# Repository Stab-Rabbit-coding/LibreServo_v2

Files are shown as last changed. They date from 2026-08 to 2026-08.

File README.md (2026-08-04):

# 

An Open source controller to convert any servo motor to the best smart servo.

This fork is focused improving the LibreServo design by moving to an TI MSPM0G3518-Q1 MCU, which provides simultaneous CAN-FD and RS485, and a robust cryptographic suite, along with an SLB9672 TPM.

**Version 4.0.0.** Upstream LibreServo shipped v2.3.1 and had a v3 in mind. The changes in this fork — new MCU family, TPM, CAN-FD alongside RS-485, an isolated transceiver pair, and a hardware security stack — go past what that v3 was scoped to be, so this fork takes the next major number rather than a v3.x that would collide with it.

**EDA tooling:** this fork has moved to **KiCad**. Autodesk EAGLE is end-of-life and no longer supported, so all new schematic and layout work is done in KiCad 9 under [`PCB/kicad/`](PCB/kicad/) as `LibreServo-v4.0.0`. The upstream EAGLE `.sch`/`.brd` files are kept in [`PCB/`](PCB/) for backward compatibility and design history; they stay frozen at v2.3.1 and are not renumbered. See [`PCB/ReadMe.md`](PCB/ReadMe.md).

This project was born as a necessity of mine to build a biped robot with intelligent servos to be able to “feel the muscles” to walk more human like. In the past we had OpenServo, and I think this project inherits something from it, but OpenServo died many years ago and it didn't reach my expectations anyway (power, communications...), and the commercial alternatives are way too expensive (Dynamixel, Herkulex, Lynxmotion...).

My goal with LibreServo is to make any standard servo the “smartest” one in the market. The "gold standard" nowadays is Robotis-Dynamixel, LibreServo should be better than that, that’s my goal at least.

A few characteristics of LibreServo:

    Compatible with standard servo motors (No need to change the bottom cover of them!)
    Voltage: From 4.5V up to 18V (Recommended: 5-14V)
    Communications: Isolated RS-485 and CAN-FD. Max Speed 9Mbps. Daisy chained. CRC-16
    Amp: Up to 16A continuous (WSD3069DN56) (Version >2.3)
    Micro-Controller (this fork): TI MSPM0G3518-Q1 (cortex-M0+@80MHz, 256KB flash, 128KB SRAM, CAN-FD + 5 UART, AES-256 with CMAC/GCM, key store, CSC secure boot). Upstream uses an STM32F301k8 (cortex-M4@72MHz).
    Trusted Platform Module: SLB9672
    Position sensor: Magnetic encoder, 16 bits of resolution! 360 degrees (AEAT-8800). Using the servo motor potentiometer will be possible to lower the cost but will lost precision and some characteristics.
    For the encoder I have designed 3D parts to substitute the potentiometer and used the same hole/space than the original.
    LibreServo will generate their own curves (sine ramps, trapezoidal ramps, hermitian curves...)
    Current sensor: +-15A ACS711
Communication Protocol: <a href="https://www.libreservo.com/en/articulo/libreservo-commands-part-one">LibreServo Commands</a><BR>


More info in <a href="https://www.libreservo.com/en">LibreServo</a>.

<p align="center">
<a href="http://creativecommons.org/licenses/by-sa/4.0/">cc-by-sa</a></p>

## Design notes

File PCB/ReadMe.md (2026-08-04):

# LibreServo v4.0.0 — PCB

**This fork is at version 4.0.0.** Upstream LibreServo shipped v2.3.1 and had a v3 in
mind; the changes made here — new MCU family, CAN-FD alongside RS-485, an isolated
transceiver pair, and a hardware security stack — go past what that v3 was scoped to be,
so the fork takes the next major number rather than a v3.x that would collide with it.

**KiCad is the primary EDA tool for this fork.** Autodesk EAGLE is end-of-life and no
longer supported, so all new schematic and layout work happens in KiCad. The EAGLE
artefacts are retained for backward compatibility with upstream LibreServo and as
design history; they are frozen at the v2.3.1 they were forked from and are not
renumbered or updated.

## Layout of this directory

| Path | Version | Tool | Status |
| --- | --- | --- | --- |
| [`kicad/`](kicad/) | 4.0.0 | KiCad 9.0.2 | **Primary — edit here** |
| `LibreServo-v2.3.1.sch` / `.brd` | 2.3.1 | EAGLE 7.6.0 | Frozen, backward compatibility |
| [`old/`](old/) | 2, 2.1, 2.2 | EAGLE 7.6.0 | Frozen, superseded upstream revisions |
| [`Gerbers/`](Gerbers/) | 2.3.1 | — | Production output, EAGLE-era |
| [`datasheets/`](datasheets/) | — | — | Local copies of vendor documents |

`kicad/LibreServo-v4.0.0.kicad_sch` and `.kicad_pcb` were produced by KiCad 9.0.2's
EAGLE importer from the frozen `.sch`/`.brd`, then carried forward independently. Both
carry `rev 4.0.0` in their title block. The Gerbers have **not** been regenerated at
4.0.0 and must not be fabricated as if they had been.

### Reading the imported symbol library

The importer names symbols after the **EAGLE symbol**, not the EAGLE deviceset, so
`kicad/LibreServo-v4.0.0-eagle-import.kicad_sym` does not always agree with the part
number. Most notably `U1` uses the symbol `MSPM0G3519` while the fitted part is a
**MSPM0G3518-Q1** (`M0G3518QRHBRQ1`). Look parts up by reference designator, not by
value.

### Known import defect: `#U1`, `#U5`, `#U6`

The three parts that had no package in the EAGLE library — `U1` (MSPM0G3518-Q1), `U5`
(ADM2587E) and `U6` (ADM3055E) — imported as `#`-prefixed pseudo-components, the class
KiCad reserves for power flags. They are consequently **absent from the exported
netlist** and are not yet real board parts. Fixing this is the first layout task; see
[`MSPM0G3518-MCU-swap.md`](MSPM0G3518-MCU-swap.md) §6.2.

## Design-change records

Each MCU / interface upgrade pass has its own decision record. Superseded records are
kept with a banner rather than deleted.

- [`MSPM0G3518-MCU-swap.md`](MSPM0G3518-MCU-swap.md) — **current**: `U1` is a TI
  MSPM0G3518-Q1 in VQFN-32 (RHB).
- [`MSPM0G3507-MCU-swap.md`](MSPM0G3507-MCU-swap.md) — superseded.
- [`S32K144-MCU-swap.md`](S32K144-MCU-swap.md) — superseded.
- [`RS485-CANFD-TPM-upgrade.md`](RS485-CANFD-TPM-upgrade.md) — superseded.

Records written on or before 2026-08-03 state that EAGLE is the project standard and
that the final product must be delivered in EAGLE, and refer to the design as v2.3.1.
**Neither is true** as of 2026-08-04; where such a record and this file disagree, this
file governs.

## Bill of materials

`LibreServo-v2.3_BOM.txt` is the EAGLE-era BOM and is several MCU generations stale.
It still lists `U1` as an `STM32F301K8U6` and predates `ADM2587E` / `ADM3055E`. It
needs regeneration from the KiCad schematic, which cannot happen until the `#U1` /
`#U5` / `#U6` defect above is fixed.

LibreServo v2.3.1 schematic, upstream

## Attribution

Upstream board design © LibreServo, CC BY-SA 4.0 — see
[LibreServo](https://www.libreservo.com/en). This fork's modifications follow the same
licence. This file was rewritten by **Claude Opus 5** (Anthropic) on 2026-08-04 at the
direction of the human maintainer, who set both the EAGLE-to-KiCad policy and the
4.0.0 version number; the original upstream text described the `.sch`/`.brd` pair and
mislabelled it as KiCad.

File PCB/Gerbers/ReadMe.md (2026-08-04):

# Gerber files to production

In the "old" folder are the old versions of LibreServo. Version 2.3.1 is the first final version.<BR>


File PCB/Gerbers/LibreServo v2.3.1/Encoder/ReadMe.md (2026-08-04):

# 

<BR>
This directory contains the gerbers of the encoder AEAT-8800 PCB (6 Layers). <BR>
To get the 4 layer version, just edit the .zip and delete the .G2 and .G3 files.

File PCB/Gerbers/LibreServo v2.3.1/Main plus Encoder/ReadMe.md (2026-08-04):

# 

<BR>
This directory contains the gerbers of the main PCB plus the encoder's PCB (6 Layers), that you can separate thanks to the "mouse bites". <BR>
To get the 4 layer version, just edit the .zip and delete the .G2 and .G3 files.

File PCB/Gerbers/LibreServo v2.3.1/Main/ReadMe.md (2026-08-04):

# 

<BR>
This directory contains the gerbers of the main PCB (6 Layers). <BR>
To get the 4 layer version, just edit the .zip and delete the .G2 and .G3 files.

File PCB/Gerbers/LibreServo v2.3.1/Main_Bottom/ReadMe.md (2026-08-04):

This is a special version ordered by a user and can only be produced in 6 layers.

#


<BR>

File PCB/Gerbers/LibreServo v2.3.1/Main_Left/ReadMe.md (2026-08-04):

# 

<BR>
This directory contains the gerbers of the main PCB with only one of the connectors on the left (6 Layers). <BR>
To get the 4 layer version, just edit the .zip and delete the .G2 and .G3 files.

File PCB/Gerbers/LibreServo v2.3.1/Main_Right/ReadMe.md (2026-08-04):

# 

<BR>
This directory contains the gerbers of the main PCB with only one of the connectors on the right (6 Layers). <BR>
To get the 4 layer version, just edit the .zip and delete the .G2 and .G3 files.

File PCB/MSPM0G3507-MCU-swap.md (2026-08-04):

# Hardware upgrade notes: MCU swap to TI MSPM0G3507-Q1 (VQFN-32), S32K144 removed

> **SUPERSEDED.** `U1` is now a TI **MSPM0G3518-Q1 (`M0G3518QRHBRQ1`)** — same MSPM0 platform,
> same VQFN-32 (RHB) package and same pinout, but the MSPM0G351x die instead of MSPM0G350x.
> See [`MSPM0G3518-MCU-swap.md`](MSPM0G3518-MCU-swap.md) for the current design.
>
> This document remains useful: §2 (package selection), §3.1–§3.5 (the pin-by-pin rationale)
> and §4 (support components) all carry over unchanged, because the MSPM0G3518's RHB-32 pad map
> is identical. What the newer part changes:
>
> - **Memory:** 128 KB/32 KB → **256 KB (dual-bank, OTA-capable) + 16 KB data flash / 128 KB SRAM**.
> - **Security:** every gap listed in §6.1 as "No" — Customer Secure Code, protected KEYSTORE,
>   flash firewalls, hardware monotonic counter, hardware AES-CMAC/CCM/GCM, hashed passwords —
>   is **present** on the MSPM0G3518. The §6.3 comparison against the S32K144 CSEc no longer
>   holds and is reversed in the new document.
> - **ADC channels** on this package: 11 → 16.

Supersedes [`S32K144-MCU-swap.md`](S32K144-MCU-swap.md), which replaced the STM32G431 with an
NXP S32K144 (LQFP48) and dropped the SLB9672 TPM in favour of the S32K144's on-chip CSEc.
This pass replaces `U1` again, with a **Texas Instruments MSPM0G3507-Q1 in the 32-pin VQFN
(RHB) package**, orderable part number **`M0G3507QRHBRQ1`**.

Local datasheet copy: [`datasheets/mspm0g3507-q1.pdf`](datasheets/mspm0g3507-q1.pdf) —
*MSPM0G350x-Q1 Automotive Mixed-Signal Microcontrollers With CAN-FD Interface*,
TI literature number **SLASF88C**, October 2023, revised September 2025.
All pin numbers, IOMUX function codes, electrical limits and mechanical dimensions below are
cited to that document; nothing here is inferred from vendor convention or community sources.

Unlike the S32K144 pass, this one is **not** a symbol-only guess: SLASF88C carries the complete
per-package pin table (§6.2, Table 6-2) and signal descriptions (§6.3, Table 6-3) in the data
sheet itself, so every pin assignment below is traceable to a specific silicon pad on a
specific package. That closes the single largest open item carried by the previous two passes.

---

## 1. Why MSPM0G3507-Q1 — and where it is a regression

Texas Instruments (USA, HQ Dallas TX). Honest scorecard against the S32K144 it replaces and
against the STM32F302K8U6 the board was originally laid out for:

| | STM32F302K8U6 (original) | S32K144 (superseded) | **MSPM0G3507-Q1 (this pass)** |
| --- | --- | --- | --- |
| Core | Cortex-M4 + FPU @ 72 MHz | Cortex-M4F @ 80/112 MHz | **Cortex-M0+, no FPU, @ 80 MHz** |
| Flash / SRAM | 64 KB / 16 KB | 512 KB / 64 KB | **128 KB (ECC) / 32 KB (parity)** |
| CAN | bxCAN, no FD | 3× FlexCAN, 1 FD | 1× CAN 2.0A/B + **CAN-FD** |
| ADC | 12-bit | 2× 12-bit | **2× 12-bit 4 Msps simultaneous**, 11 ch on this package |
| Other analog | — | — | **1× 12-bit DAC, 2× zero-drift chopper OPA, 3× COMP, GPAMP, internal VREF** |
| Crypto | — | **CSEc (SHE-class HSM)** | AES-128/256, TRNG, CRC — **no HSM** |
| Auto qual | — | ISO 26262 ASIL-B capable | **AEC-Q100 Grade 1**, ISO 26262 ASIL-B, TÜV certified |
| Smallest package | UFQFPN-32, 5 × 5 mm | **LQFP-48, 9 × 9 mm** | **VQFN-32, 5 × 5 mm** |

**Two regressions must be stated plainly, because both are one-way doors:**

1. **The FPU is gone.** Cortex-M0+ has no floating-point unit and no DSP instructions
   (SLASF88C §1 "Core", §8.1). The original STM32F302 *did* have one. `Src/LS_*.c` runs PID
   and curve generation; any `float`/`double` math in that code becomes soft-float library
   calls. Partial mitigation is on-die: SLASF88C §1 lists a **math accelerator (MATHACL)
   supporting DIV, SQRT, MAC and TRIG** (§8 block diagram, `MATHACL` on the CPU-only PD1 bus),
   which is the intended substitute — but taking advantage of it means **reworking the control
   loop in fixed-point**, not recompiling. Budget for that explicitly.
2. **The hardware key store is gone — but secure boot is not.** See §6 for the full,
   corrected treatment. In short: the MSPM0G3507 *does* have a ROM-anchored secure boot with
   **asymmetric ECDSA P-256** image authentication, which is something CSEc (symmetric-only
   SHE) could never do. What it genuinely loses versus CSEc is the **protected key store**, the
   **hardware monotonic counter** (so no hardware rollback protection), and **hardware
   AES-CMAC**.

Against that, the wins that motivate the swap are real: it is the only candidate so far that
**fits the existing 5 × 5 mm board footprint envelope** (the S32K144's smallest package was
9 × 9 mm, an unresolved open item in the previous pass), it brings native CAN-FD, it is
AEC-Q100 Grade 1, and its analog integration (dual simultaneous 4 Msps ADC, chopper OPAs,
comparators with 8-bit reference DACs) is directly useful for motor current sensing.

## 2. Package selection: 32-pin VQFN (RHB), 5 × 5 mm

Requirement is **24 GPIO**: the 21 signals `U1` already carried, plus `HFCLK_IN` for the
existing 8 MHz oscillator, plus `VREF+` and `VREF-`. Audited against Table 6-2's per-package
availability columns:

| Package | Body | GPIO (Table 5-1) | Spares | Verdict |
| --- | --- | --- | --- | --- |
| 28 VSSOP (DGS28) | 7.1 × 3 mm | 24 | **0** | Fits, but every pin committed; no thermal pad; `PA7`/`PA8`/`PA12`/`PA13` not bonded, forcing CAN onto `PA26`/`PA27` and consuming `PA2`/`ROSC` and `PA5`/`HFXIN` as plain GPIO |
| **32 VQFN (RHB)** | **5 × 5 mm** | **28** | **4** | **Selected** |
| 32 VSSOP (DGS32) | 8.1 × 4.9 mm | 28 | 4 | Same pin count, larger area, no thermal pad |
| 48 VQFN / 48 LQFP | 7 × 7 / 9 × 9 mm | 44 | 20 | Oversized for this board |

**Decision: `RHB`, the 32-pin VQFN.** It is not the smallest by raw area — DGS28 is 21.3 mm²
against RHB's 25.0 mm² — but DGS28 lands at exactly 24 of 24 GPIO with zero margin, which is
the same zero-spare condition that both previous upgrade passes flagged as a recurring problem.
RHB also has an **exposed thermal pad**, so the symbol's existing `EP`-to-`GND` connection
survives, and the 5 × 5 mm body matches the UFQFPN-32 the board outline was drawn around.
32- and 48-pin QFN are additionally available with **wettable flanks** (SLASF88C §1
"Automotive qualification"), which is useful for the AOI/inspection requirements that usually
accompany an AEC-Q100 build.

### 2.1 The existing `QFN32` footprint is NOT reusable

Worth stating explicitly, because both parts are "32-pin, 5 × 5 mm, 0.5 mm pitch QFN" and the
substitution looks safe:

| | Propio `QFN32` (in use for STM32F301/2) | TI `RHB0032E` (SLASF88C §12, drawing 4223442/B) |
| --- | --- | --- |
| Pad 1 location | bottom row, left end | **left column, top** |
| Numbering | bottom → right → top → left | **left → bottom → right → top** |
| Pad size | 0.7 × 0.3 mm | **0.6 × 0.25 mm** |
| Row-to-row span | 5.5 mm | **4.8 mm** |
| Thermal pad | 3.45 × 3.45 mm | 3.45 × 3.45 mm (pad 33) |

The pad numbering differs by a 90° rotation and the land span is 0.7 mm larger. Only the
thermal pad happens to match. **A new footprint is required** — do not bind the deviceset to
`QFN32`. TI's recommended land pattern is fully dimensioned in §12 and is reproduced above.

## 3. `U1` pin assignment

Every row is cited to SLASF88C Table 6-2 (column *48 LQFP, VQFN* → *32 VQFN* pin number) and
its bracketed `PINCM.PF` IOMUX function code. Pins marked *(spare)* are unconnected, terminated
per Table 6-4 ("PAx and PBx — Open; set corresponding pin functions to GPIO and configure
unused pins to output low or input with the internal pullup or pulldown resistor enabled").

| Pad | Pin | Net | Function (PF) | IO type | Notes |
| ---: | --- | --- | --- | --- | --- |
| 1 | `PA0` | `LED_RED` | GPIO [PF1] | **5 V-tol. open drain** | see §3.1 |
| 2 | `PA1` | — | *(spare)* | 5 V-tol. open drain | |
| 3 | `NRST` | `NRST` | reset | Reset | **must be pulled high** — §4 |
| 4 | `VDD` | `+3V3` | power | Power | |
| 5 | `VSS` | `GND` | power | Power | |
| 6 | `PA2` | — | *(spare)* | Standard | also `ROSC`; SYSOSC FCL option preserved |
| 7 | `PA3` | `LED_GREEN` | GPIO [PF1] | Standard | |
| 8 | `PA4` | `PWM-4` | `TIMA0_C3` [PF5] | Standard | → `M4.INA` |
| 9 | `PA5` | `EN-Q` | GPIO [PF1] | Standard | driver enable, `R11`/`R12` |
| 10 | `PA6` | `CLK-8MHZ` | **`HFCLK_IN`** [PF7] | Standard | from oscillator `U$100` — §3.2 |
| 11 | `PA7` | `LED_BLUE` | GPIO [PF1] | Standard | |
| 12 | `PA8` | — | *(spare)* | Standard | |
| 13 | `PA9` | `SEL_SERIAL` | GPIO [PF1] | High-Speed | RS-485 `DE`+`RE` turnaround |
| 14 | `PA10` | `UART0_TX` | `UART0_TX` [PF2] | High-Drive | default BSL `UART_TX` — §3.3 |
| 15 | `PA11` | `UART0_RX` | `UART0_RX` [PF2] | High-Drive | default BSL `UART_RX` |
| 16 | `PA12` | `CAN_TX` | `CAN_TX` [PF5] | High-Speed | → `U6.TXD` (ADM3055E) |
| 17 | `PA13` | `CAN_RX` | `CAN_RX` [PF6] | High-Speed | → `U6.RXD` |
| 18 | `PA14` | — | *(spare)* | High-Speed | also `A0_12` |
| 19 | `PA15` | `V_CORRIENTE` | `A1_0` (analog, PF0) | Standard | **ADC1** — §3.4 |
| 20 | `PA16` | `SPI_IN` | `SPI1_POCI` [PF3] | Standard | |
| 21 | `PA17` | `SPI_CLK` | `SPI1_SCK` [PF3] | Standard | |
| 22 | `PA18` | `SPI_OUT` | `SPI1_PICO` [PF3] | Standard | |
| 23 | `PA19` | `SWDIO` | `SWDIO` [PF2] | High-Speed | dedicated |
| 24 | `PA20` | `SWCLK` | `SWCLK` [PF2] | Standard | dedicated |
| 25 | `PA21` | `GND` | **`VREF-`** (analog) | Standard | §3.5 |
| 26 | `PA22` | `PWM-2` | `TIMA0_C1` [PF5] | Standard | → `M5.INA` |
| 27 | `PA23` | `VDDA-FILTRADO` | **`VREF+`** (analog) | Standard | §3.5 |
| 28 | `PA24` | `PWM-3` | `TIMA0_C3N` [PF4] | Standard | → `M4.INB` |
| 29 | `PA25` | `PWM-1` | `TIMA0_C1N` [PF6] | Standard | → `M5.INB` |
| 30 | `PA26` | `V_TEMP` | `A0_1` (analog, PF0) | Standard | ADC0 |
| 31 | `PA27` | `V_BAT` | `A0_0` (analog, PF0) | Standard | ADC0 |
| 32 | `VCORE` | `VCORE` | core LDO | Power | **0.47 µF tank cap only** — §4 |
| 33 | thermal pad | `GND` | — | — | symbol pin `PAD` |

**Spares: `PA1`, `PA2`, `PA8`, `PA14` (4).** For the first time since the STM32F302, `U1` is
not fully pinned out.

### 3.1 `LED_RED` is deliberately on an open-drain pin

The RGB indicator is **common-anode** (`RGB.CAT_RED/GREEN/BLUE` are the cathodes, fed through
`R6`/`R7`/`R8`), so the MCU **sinks** LED current. `R6` = 187 Ω is much smaller than `R7`
(270 Ω) and `R8` (309 Ω), making red the highest-current channel: on a 3.3 V rail with a
typical red Vf of 1.8–2.2 V that is roughly **6–8 mA**, which straddles or exceeds the **6 mA**
absolute-maximum limit for a Standard-drive pin (Table 7-1, "Current of SDIO pin").

`PA0` and `PA1` are the package's two **5 V-tolerant open-drain** pins, rated **20 mA sink**
(Table 7-1, "Current of ODIO pin"). Their structure — low-side NMOS only, no high-side PMOS
(§9.1) — is exactly right for pulling an LED cathode down, and needs no pull-up because the
LED and its resistor to `+3V3` *are* the load. `LED_RED` therefore lands on `PA0`.
Green and blue draw roughly 1–2.5 mA and stay on Standard-drive pins.

*Firmware note:* `PA0`/`PA1` are also the default BSL I²C pins (Table 6-2). If the BSL is
entered, the red LED may flicker. Harmless — the pin is open-drain either way.

### 3.2 Clock: external square wave, not a crystal

`CLK-8MHZ` is driven by oscillator module `U$100` (`OSC-2X1.6`), i.e. a digital square wave,
not a crystal. The correct destination is therefore **`HFCLK_IN` on `PA6` [PF7]**, the digital
external-clock input, not the `HFXIN`/`HFXOUT` crystal pair. SLASF88C §1 lists "External clock
input" alongside the 4–48 MHz crystal option. The S32K144 symbol's `XTAL` pin had no function
and is deleted, along with its `NC_MARKER` (`U$15`).

Consequence: `PA6` is the only `HFCLK_IN`-capable pin, so committing it forecloses using a
crystal later without re-pinning. `PA5`/`HFXIN` is left as a plain spare-adjacent Standard pin.

### 3.3 RS-485 UART sits on the default BSL pins, deliberately

`UART0_TX`/`UART0_RX` on `PA10`/`PA11` are marked "(Default BSL UART_TX)" / "(Default BSL
UART_RX)" in Table 6-2. Per §8.33 the BSL is **automatically invoked when the reset vector and
stack pointer are unprogrammed**, so a virgin device is reachable over the RS-485 pins with no
BSL-invoke strap and no debug probe. Nothing else competes for these two pins.

**Caveat, so nobody plans around a capability that isn't there:** the BSL ROM drives only
`BSLRX`/`BSLTX`. It does *not* drive `SEL_SERIAL`, which gates the ADM2587E's `DE`/`RE`. With
`SEL_SERIAL` undriven and pulled low by `R20`, the transceiver sits in receive-only mode, so
the BSL's replies never reach the bus — programming over the daisy chain would need a fixture
that asserts `DE` externally. The upside is that this arrangement is also **safe**: a blank
board cannot babble onto a live RS-485 bus.

### 3.4 ADC channel split

`V_CORRIENTE` is the time-critical measurement for the control loop, so it is placed on
**ADC1** (`A1_0`, `PA15`) while `V_TEMP` and `V_BAT` share **ADC0** (`A0_1`, `A0_0`). The two
converters are simultaneous-sampling (SLASF88C §1), so current can be captured in lockstep
with a bus/temperature sample rather than serialised behind it.

`PA15` additionally exposes `OPA1_IN2+`, `COMP0_IN3+` and `COMP1_IN3+`. That leaves the option
open to route the ACS711 current signal through a chopper OPA gain stage, or into a comparator
with its 8-bit reference DAC for a **hardware overcurrent trip**, with no board change beyond
firmware — worth considering, since `EN-Q` is already a hard driver-disable.

### 3.5 `VDDA-FILTRADO` now feeds `VREF+`

The MSPM0G3507 has **no separate `VDDA` pin** — a single `VDD` supplies the die. The board's
existing filtered analog rail (`B1` ferrite + `C4` 1 µF + `C5` 100 nF) would otherwise have
nowhere to land, and the ADC would lose its clean reference.

It is therefore wired to **`VREF+` (`PA23`)**, with **`VREF-` (`PA21`)** tied to `GND`. This is
exactly TI's characterised external-reference condition: SLASF88C §7.12.3 note (2) states that
all external reference specifications are measured with *"V<sub>R+</sub> = VREF+ = VDD and
V<sub>R−</sub> = VSS = 0 V, external 1 µF cap on VREF+ pin"*. It also preserves the
**ratiometric** behaviour the existing `R4`/`R5` battery divider and current-sense scaling were
designed around, which switching to the internal 1.4 V / 2.5 V reference would break.

**The required decoupling already exists:** §7.15.2 specifies C<sub>VREF</sub> = 0.7–1.15 µF
(1 µF typical, 0805 or smaller ceramic, ±20 % acceptable) from `VREF+` to `VREF-`/`GND`.
`C4` is already a 1 µF 0402 on that rail. No new part needed — but `C4` is now a
**functional requirement**, not just supply filtering, and must be placed tight to pad 27.

*Firmware note:* §7.12.3 note (3) — external and internal reference modes are mutually
exclusive. The internal VREF buffer must stay disabled, or it will fight the external rail.

## 4. New support components (all mandatory)

Three parts are added. None were needed by the S32K144 or the STM32 parts before it, and two
of them will stop the board booting if omitted.

| Ref | Value | Net | Requirement |
| --- | --- | --- | --- |
| `R21` | 47 kΩ 0402 | `NRST` → `+3V3` | **`NRST` must be pulled to VDD or the device cannot start** (Table 6-4; §9.1: *"NRST **must** be pulled to VDD for the device to start"*). 47 kΩ is TI's recommended value. |
| `C40` | 10 nF 0402 | `NRST` → `GND` | TI-recommended `NRST` filter (§9.1), keeping the pin controllable by a debug probe. |
| `C39` | 470 nF 0402 | `VCORE` → `GND` | §9.1: *"A 0.47 µF tank capacitor is required for the VCORE pin and must be placed close to the device with minimum distance to the device ground. **Do not connect other circuits to the VCORE pin.**"* |

This is a behavioural change worth calling out: the board has **never** had a reset pull-up.
`PG10-NRST` on the STM32G431 and `RESET_b` on the S32K144 were both deliberately left
no-connect, relying on internal pull-ups, and that was a documented design decision. It is no
longer valid — on this device an undriven `NRST` means a dead board. Both `NC_MARKER`s
(`U$15`, `U$16`) that terminated `XTAL` and `RESET_b` are deleted.

`VCORE` (pad 32) is the internal 1.35 V core-LDO output (§7.3: V<sub>CORE</sub> = 1.35 V).
It is **not** a supply input — it must never be tied to `+3V3`.

## 5. What changed in the schematic

`PCB/LibreServo-v2.3.1.sch` (EAGLE 7.6 XML) was edited directly:

- **Library:** symbol and deviceset `S32K144` replaced by `MSPM0G3507`. The symbol keeps every
  retained pin at the **same x/y coordinate** it occupied on the S32K144 symbol, so no existing
  wire had to move; pins were renamed onto real MSPM0 port/function names. Four spare pins were
  added at previously-unused symbol positions, all verified to sit on empty sheet coordinates.
- **`U1`** retargeted to `MSPM0G3507`, value `M0G3507QRHBRQ1`.
- **Pins removed:** `VDD_2` and `VSS_2` (the MSPM0 has one `VDD` and one `VSS` plus the thermal
  pad, not two of each) — their stub wires and now-redundant junctions were removed, leaving
  `C1`/`C2`/`C3`/`SUPPLY24`/`+3V14` connected exactly as before. `XTAL` removed (§3.2).
- **Pins added:** `VCORE`, `NRST`, `VREF+`, `VREF-` and the four spares.
- **Nets added:** `VCORE`, `NRST`, plus the `GND` and `+3V3` segments for `C39`/`C40`/`R21`.
- **Nets deleted:** `N$10`, `N$11` (the two no-connect nets).
- **Nets renamed** to TI peripheral naming — connectivity unchanged, labels follow the net:

  | Before | After |
| --- | --- |
  | `LPUART1_TX` / `LPUART1_RX` | `UART0_TX` / `UART0_RX` |
  | `CAN0_TX` / `CAN0_RX` | `CAN_TX` / `CAN_RX` |
  | `SWD_DIO` / `SWD_CLK` | `SWDIO` / `SWCLK` |

- **Sheet annotation** updated (MCU banner and the security note that previously described CSEc).

### Verification performed

Machine-checked against the edited file with a purpose-written connectivity checker that
applies EAGLE's own rules (wires join at shared endpoints; a junction or a pin lying on a wire
also joins it), not eyeballed:

1. **XML well-formed** (`xml.etree` parse).
2. **All 29 connected `U1` pins land on the intended net**, every one of the 33 symbol pins
   resolves to a real package pad, and the 4 unconnected pins are exactly the intended spares.
3. **Zero coincident connection points between different nets**, across the entire sheet —
   every wire endpoint, junction and pin coordinate resolved, including instance rotation.
4. **Zero pins lying on a foreign net's wire.** This is the check that catches a rail drawn
   straight through a component pin; it found 18 such defects on entry and all are now fixed
   (§10).
5. **Zero net segments split into disconnected fragments.**
6. **Zero unresolved `pinref`s** — every one maps to an existing instance and symbol pin.

Crossings *without* a shared point are left alone: they are normal schematic practice and carry
no connectivity meaning. The `NRST` trunk, for instance, deliberately crosses the two long
pre-existing diagonal wires (`GND` and `VDDA-FILTRADO`).

The geometry-only repairs in §10 were additionally proved safe by extracting the full
`part.pin → net` list before and after: **all 399 connections are byte-identical.**

## 6. Security: corrected assessment

An earlier revision of this document claimed the MSPM0G3507 had "no ROM-enforced secure boot".
**That was wrong.** The authoritative source is TI application note **SLAAE29A**, *Cybersecurity
Enablers in MSPM0 MCUs* (January 2023, revised December 2025), local copy at
`../../Open-Secure-ESC/docs/datasheets/slaae29a.pdf`. The MSPM0G3507 sits in that document's
**`M0G3x0x/M0G150x`** column of Table 1-2, "MSPM0 MCU Platform Security Enablers".

### 6.1 What this device actually has

| Capability | MSPM0G3507 | Source |
| --- | --- | --- |
| Immutable ROM root of trust (BCR) | **Yes** | SLAAE29A §2.3 |
| Single point of entry to main flash at boot | **Yes** | Table 1-2 |
| CRC-32 verified main flash region | **Yes** | Table 1-2 |
| **Asymmetric image auth (ECDSA P-256 + SHA2-256, software)** | **Yes** | Table 1-2 |
| Secure boot solution | **BIM** (Boot Image Manager, MCUboot-based) | §3.3 |
| Permanently lockable main flash | **Yes** | Table 1-2 |
| SRAM write-execute mutual exclusion (W^X) | **Yes** | Table 1-2, §4.6 |
| Password-authenticated debug / BSL / mass erase / factory reset | **Yes** | Table 1-2 |
| Complete hardware disable of SWD | **Yes** | Table 1-2 |
| TRNG with power-on and continuous self-test | **Yes** | Table 1-2, §5.2 |
| AES accelerator (basic) | **Yes** — ECB, CBC, OFB, CFB, CTR, CBC-MAC | Table 5-1 |
| 96-bit unique device identifier | **Yes** | Table 1-2, §2.1 |
| EVITA capability | **EVITA-Light** | Table 1-2 |
| Customer Secure Code (CSC) / INITDONE | No | Table 1-2 |
| **Protected key store (KEYSTORE)** | **No** — requires CSC | Table 1-2, §4.5 |
| Flash firewalls (write / read-execute / IP protection) | No — require CSC | Table 1-2 |
| **Hardware monotonic counter** (rollback protection) | **No** | Table 1-2, §4.7 |
| Hardware AES-CMAC / CCM / GCM (AESADV) | No | Table 5-1 |
| Passwords stored hashed (SHA2-256) | No — stored in NONMAIN | Table 1-2 |

AES throughput, for firmware budgeting (Table 5-2, at 80 MHz): 128-bit key 168 cycles
(2.10 µs) per block encrypt or decrypt; 256-bit key 234 cycles (2.93 µs).

### 6.2 Secure boot via BIM

Because this die has no CSC, the applicable secure boot solution is **BIM**, supplied in the
MSPM0 SDK (SLAAE29A §3.3). It is MCUboot-derived: two application image slots (primary and
secondary) at fixed flash addresses, images signed with MCUboot's `imgtool`, and at each boot
the BIM verifies the candidate slot with **SHA-256 + ECDSA**; on failure it erases that slot
and falls back to the other, failing closed if neither verifies (§3.3.1, Figure 3-13).

Provisioning, per §3.3.1, requires all of: the BIM firmware and its authentication keys placed
in MAIN flash with the reset vector at `0x0000.0004` pointing at BIM; those sectors and the
NONMAIN sector set **static write protected**; mass erase and factory reset **password
protected or disabled**; and the MAIN flash memory integrity check enabled over the BIM and key
region. Note §3.3.1(c): disabling factory reset alongside those settings makes the NONMAIN
configuration **permanently locked** — a genuine one-way door on a production unit.

### 6.3 Honest comparison with the S32K144 CSEc it replaces

| | S32K144 CSEc | MSPM0G3507 |
| --- | --- | --- |
| Secure boot | Hardware AES-CMAC over image | ROM-anchored BIM, SHA-256 + ECDSA P-256 |
| **Asymmetric signing / verification** | **No** (SHE is symmetric-only) | **Yes — ECDSA P-256** |
| Protected key store | **Yes** (SHE key slots) | **No** |
| Rollback protection | SHE counters | **No** hardware monotonic counter |
| Hardware CMAC | Yes | No (CBC-MAC only) |
| TRNG | Yes | Yes, with self-test |
| Debug lockdown | Yes | Yes, incl. permanent SWD disable |

So this is **not** a straight downgrade. The MSPM0 *gains* public-key image authentication,
which is the capability the README's "cryptographic authentication and message signing" claim
actually needs and which CSEc could not provide. It *loses* hardware key protection and
rollback protection: signing keys are public keys (fine in flash), but any **private** key or
shared secret the application holds lives in ordinary flash, protected only by static write
protection, debug lock and BSL lockout — not by a key store the CPU cannot read.

**README claims still needing correction:** "post-quantum" remains unsupportable (P-256 is
classical ECC, and there is no PQC support anywhere in this part). "Trusted Platform Module" is
also gone as of the S32K144 pass. "Cryptographic authentication and message signing" is now
defensible in software.

## 7. Isolated transceivers: verified pin maps and the `GND2`/`GNDISO` split

Verified pin maps for both isolated transceivers were supplied from the sibling `Open-Secure-ESC`
project (`symbols/specs/ADM2582E_ADM2587E.json`, `symbols/specs/ADM3055E_ADM3057E.json`). Both
were **re-checked here against the local ADI datasheets** rather than taken on trust:

- ADM2582E/ADM2587E Rev. H, p.8, Table 10 — matches the JSON exactly.
- ADM3055E/ADM3057E Rev. D, p.15, Table 10 — matches the JSON exactly.

The existing hand-authored EAGLE symbols for `U5` and `U6` were checked against those maps and
**every distinct pin name is correct**. The only modelling defect was on the ADM2587E, below.

### 7.1 ADM2587E `GND2` was one pin where the silicon has two grounds

`U5`'s symbol collapsed all four `GND2` pads (11, 14, 16, 20) onto a single schematic pin.
That is not merely cosmetic: Table 10 says of **pin 16** — *"Ground, Bus Side. **Do not connect
this pin to Pin 14 and Pin 11.**"* — while pins 11 and 14 are the isolated DC-DC converter
ground, which Table 10 says to *"connect ... together through one ferrite bead to PCB ground"*.
With one collapsed pin, that separation could not be expressed in the netlist at all.

The ADM3055E gives the same two nodes distinct mnemonics (`GND2` for pads 11/15, `GNDISO` for
pads 18/20), and `U6` was already wired correctly with ferrite `B5` between them. `U5` is now
modelled the same way:

- symbol pin `GND2` → pads **16, 20** (bus side) → net `RS485_ISO_GND`
- new symbol pin `GNDISO` → pads **11, 14** (converter side) → new net `RS485_GNDISO`
- new ferrite **`B7`** bridges the two, mirroring `B5` on the CAN side

### 7.2 isoPower reservoir capacitors re-referenced

Both datasheets are explicit about *which* ground the `VISOOUT` reservoir pair returns to, and
both boards had it wrong — the ripple was returning through the ferrite instead of locally to
the converter ground, which defeats the point of fitting the ferrite:

| Cap pair | Was | Now | Datasheet |
| --- | --- | --- | --- |
| `C27` 10 µF + `C28` 100 nF (`U5` VISOOUT) | `RS485_ISO_GND` | **`RS485_GNDISO`** | ADM2587E Table 10 pin 12: *"a reservoir capacitor of 10 µF and a decoupling capacitor of 0.1 µF be fitted between Pin 12 and Pin 11"* |
| `C35` 220 nF + `C36` 10 µF (`U6` VISOOUT) | `CANFD_ISO_GND` | **`CANFD_GNDISO`** | ADM3055E Table 10 pin 19: *"requires 0.22 µF and 10 µF capacitors to GND_ISO"* |

`C29`/`C30` (`U5` VISOIN) and `C37`/`C38` (`U6` VISOIN) were already correct on the bus-side
ground, per ADM2587E Table 10 pin 19 (*"between Pin 19 and Pin 20"*).

## 8. CAN-FD bus connectors

The CAN-FD bus connector decision, open since the `RS485-CANFD-TPM-upgrade.md` pass, is now
resolved and on-sheet. `CANH`/`CANL` were previously labelled but unterminated and went nowhere.

**`U$26` (CAN-FD IN) and `U$27` (CAN-FD OUT)** — a daisy-chain pair mirroring the RS-485
connectors `U$8`/`U$9`, on a new `JST_PH-3_HOLE` deviceset:

| Pin | Net | Rationale |
| --- | --- | --- |
| `P$1` | `CANFD_ISO_GND` | ISO 11898-2 bus reference. An isolated node whose bus side floats has an undefined common-mode voltage relative to other nodes; the CAN_GND conductor is what bounds it. This is why CANopen/DeviceNet cabling carries CAN_GND. |
| `P$2` | `CANL` | kept adjacent to `CANH` for twisted-pair continuity up to the shell |
| `P$3` | `CANH` | |

**Why 3-way and not 4-way.** The obvious move was to reuse the existing `JST_PH-4_HOLE`, which
already has a footprint and is already in the BOM. It was rejected deliberately: the RS-485
daisy-chain connectors are 4-way JST-PH **carrying `+7V` on `P$1`**. A 4-way CAN port would be
physically cross-mateable with them, and plugging an RS-485 cable into a CAN port would drive
`+7V` straight onto the isolated CAN bus and its ground reference. A 3-way shell makes that
mistake impossible by construction, which is worth more than connector-family commonality on a
board whose whole reason for using isolated transceivers is fault tolerance.

**Termination.** `R22`/`R23` (60.4 Ω) and `C41` (4.7 nF) form a **split termination** from
`CANH` to `CANL` with the midpoint (`CAN_SPLIT`) bypassed to `CANFD_ISO_GND` — the standard
arrangement, which damps common-mode as well as differential energy. All three are marked
**`DNP` (do not populate)** in their value fields: CAN is a linear bus and only the two
physical **end** nodes may be terminated. A mid-chain servo with termination fitted will load
the bus and break it. Populate on end nodes only.

Note the RS-485 side has **no** termination provision at all, which is a pre-existing gap — see
§10.

## 9. Firmware impact

The port is again a full rewrite, and larger than the S32K144 estimate implied:

- Toolchain moves to **TI's MSPM0 SDK / SysConfig** with Code Composer Studio, IAR, Keil or
  TI Arm-Clang (§10.3). `Test_LibreServo_v2.ioc` (STM32CubeMX) and `STM32F302K8UX_FLASH.ld`
  are dead artefacts.
- **Peripheral remap:** `TIMA0` (advanced timer, deadband-capable) for motor PWM, `UART0`,
  `SPI1`, `ADC0`/`ADC1`, `CANFD`, IOMUX `PINCMx` register configuration per pin.
- **Motor PWM can now use true complementary pairs with deadband.** `PWM-2`/`PWM-1` are
  `TIMA0_C1`/`C1N` and `PWM-4`/`PWM-3` are `TIMA0_C3`/`C3N` — matched complementary channels on
  the same advanced timer (SLASF88C §1: *"Two 16-bit advanced control timers with deadband
  support and complementary outputs"*). The previous designs had no such pairing. Whether the
  H-bridge is driven as complementary PWM or as PWM+direction is now a firmware choice rather
  than a hardware constraint.
- **The SPI bus can become hardware SPI1.** `SPI_CLK`/`SPI_OUT`/`SPI_IN` are on
  `SPI1_SCK`/`SPI1_PICO`/`SPI1_POCI`. It was bit-banged GPIO on every previous MCU. Still
  shared with connector `U$4` and `POTEN_SERVO` (`U$6`) — the open question from the previous
  passes about what else lives on that bus is **still open** and still gates using it.
- **Fixed-point rework of the control loop** — see §1.

## 10. Still open

Carried forward, plus new items from this pass.

**New, from this pass:**

- [ ] **Footprint/package for `MSPM0G3507` (RHB0032E)** — deviceset is symbol-only. Do not
      reuse `QFN32`; see §2.1 for why, and for TI's dimensioned land pattern.
- [ ] **`.brd` placement for `U1`** — the existing `U1` element still references package
      `QFN32` at `x=4.78 y=8.4 rot=R270`. Body size is unchanged at 5 × 5 mm, so the envelope
      fits, but the pad numbering is rotated and the land geometry differs.
- [ ] **`C1` bulk decoupling is below spec.** §7.3 lists C<sub>VDD</sub> = 10 µF between `VDD`
      and `VSS`, and §9.1 recommends 10 µF + 0.1 µF placed within a few millimetres. `C1` is
      **4.7 µF** in an 0402. Raising it to 10 µF in 0402 is possible but severely
      derated at 3.3 V — this is a real BOM/footprint decision (larger case size vs. accepting
      4.7 µF), deliberately not changed silently here.
- [ ] **Rewrite the README security claims** — see §6.3 for exactly which claims are now
      defensible and which are not.
- [ ] Confirm the FPU loss and the fixed-point rework are acceptable, or reconsider the part.
- [ ] **Footprint for the new `JST_PH-3_HOLE` CAN connectors** (`U$26`/`U$27`) — symbol-only
      deviceset; the land pattern is a one-position derivative of the existing
      `JST_PH-4_HOLE_B`. Silkscreen must clearly distinguish the CAN ports from the RS-485
      ports (see §8).
- [ ] **BIM secure-boot provisioning plan** — key generation and custody, `imgtool` signing in
      the build, and the NONMAIN static-write-protect / factory-reset-disable step, which is
      **permanent** (SLAAE29A §3.3.1c). Needed before anything ships beyond a bench prototype.
- [ ] **No RS-485 termination provision exists** on this board (the CAN side now has a DNP
      split termination; `RS485_P`/`RS485_N` have nothing). Decide whether end-of-chain servos
      need a fitted or switchable 120 Ω across the RS-485 pair.

**Pre-existing schematic-geometry defects — found and FIXED by this pass:**

A connectivity checker written for this work found **14 places where a pin sat on top of a
foreign net's wire**, plus **3 net-connectivity breaks**, all inherited from the
`RS485-CANFD-TPM-upgrade.md` pass. All are now repaired. What they were, and how each was fixed:

| # | Defect | Fix |
| ---: | --- | --- |
| 1–6 | The `GND` wire `(33.02,-44.45)→(33.02,-60.96)` ran straight down `U5`'s **entire logic-side pin column**, passing through `VCC`, `RxD`, `RE`, `R20.1`, `DE` and `TxD` | `GND` is a supply net joined by name, so the wire was unnecessary. Deleted it and placed `SUPPLY37` directly on `U5.GND1` |
| 7–8 | `RS485_VISOOUT`'s cap feed ran along `y=-88.9` from `x=86.36`, straight through `C25.1` and `C26.1` (`+3V3`) — **bridging the isolation barrier** on the drawing | Rerouted: drops at `x=104.14`, i.e. to the right of the `+3V3` pair, and spans only `C27.1`–`C28.1` |
| 9–11 | `RS485_VISOIN`'s cap feed ran along `y=-88.9` from `x=93.98` through `C26.1`, `C27.1` and `C28.1`, and its riser passed through `+3V15`'s pin at `(93.98,-86.36)` | Rerouted along `y=-73.66`, dropping at `x=124.46`, spanning only `C29.1`–`C30.1` |
| 12–13 | `C37`/`C38`'s pin-2 risers ran **up** to the `y=-183.51` ground trunk, passing straight through their own pin 1 — shorting both capacitors | Ground now approaches from **below** via `x=144.78` and `y=-200.66`, the same pattern already used correctly for `C33`/`C34` |
| 14 | `+3V15`'s pin sat on the `RS485_VISOIN` riser | resolved by the same reroute as 9–11 |
| — | `CANFD_ISO_GND` was split into **two disconnected fragments** by a 2.54 mm gap at `y=-183.51` (`U6.GND2`+`B5.2` isolated from `U6.RS` and the caps) | gap closed |
| — | NC markers `U$24`/`U$25` sat **7.62 mm away** from `U6.AUXIN`/`AUXOUT`, leaving both `N$20` and `N$21` as two fragments | markers moved onto their pins |

**The declared netlist is provably unchanged by this cleanup:** all 399 `part.pin → net`
connections are byte-identical before and after. These were geometry-only repairs.

The schematic now passes all four structural checks with zero findings — see §5.

**Still open in this area:**

- [ ] **`U6.AUXIN` (pad 9) is left floating.** ADM3055E Table 10 documents internal pull-downs
      for `SILENT` and `STBY` but **not** for `AUXIN`, so the "may be left unconnected"
      assumption carried over from the previous pass is not supported by the datasheet. A
      floating CMOS input should be tied — recommend `AUXIN` → `GND1`. Not changed here because
      it alters the netlist rather than the drawing, and the auxiliary channel's intended use
      (if any) is a design decision. `AUXOUT` is an output and is fine left open.

**Carried over, still unresolved:**

- [ ] Footprints/devicesets/3D models and `.brd` placement for `ADM2587E` (`U5`) and
      `ADM3055E` (`U6`).
- [ ] **5 V rail for `U6`'s isoPower `VCC`** (`+5V_ISO_CANFD`) — nothing on the board produces
      5 V; a regulator must be selected and added.
- [ ] Confirm what else is live on the shared `SPI_CLK`/`SPI_IN`/`SPI_OUT` bus (`U$4`, `U$6`)
      before enabling hardware SPI1 on it.
- [ ] Isolation creepage/clearance for the two SOIC-20 isolated parts against the board outline.
- [ ] At layout, keep `U5` pad 16 off the same copper as pads 11/14 — now expressible in the
      netlist (§7.1), but the physical separation is still a layout obligation.
- [ ] Whether the shared `Vmot`/`GND` on the daisy-chain connector undermines the RS-485
      isolation (see `RS485-CANFD-TPM-upgrade.md` §2).

**Repository hygiene (pre-existing, not introduced here):**

- [ ] `PCB/LibreServo-v2.3_BOM.txt` is **two MCU generations stale** — it still lists `U1` as
      `STM32F301K8U6` / `QFN32` and contains none of `ADM2587E`, `ADM3055E`, or the support
      parts added by the last three passes. It was not updated by this pass either, because a
      partial edit would be more misleading than an obviously-stale file. It needs a full
      regeneration from the schematic.
- [ ] This repository has no `CLAUDE.md`/`AGENTS.md`, `TODO.md`, `REFERENCES.md` or
      `PROJECT_INDEX.md`. Citations in this document therefore follow the existing in-repo
      convention (inline, with the local datasheet path and TI literature number) rather than
      REF-IDs.

---

## Attribution

Schematic edit, pin assignment, package selection and this document produced by
**Claude Opus 5** (Anthropic), working from the local TI datasheet copy
`PCB/datasheets/mspm0g3507-q1.pdf` (SLASF88C). Package choice between 28-VSSOP and 32-VQFN was
decided by the human maintainer. Prior passes are recorded in
[`S32K144-MCU-swap.md`](S32K144-MCU-swap.md) and
[`RS485-CANFD-TPM-upgrade.md`](RS485-CANFD-TPM-upgrade.md).

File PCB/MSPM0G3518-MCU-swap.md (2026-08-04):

# Hardware upgrade notes: MCU is TI MSPM0G3518-Q1 (VQFN-32, RHB)

**Current design.** `U1` is a **Texas Instruments MSPM0G3518-Q1** in the 32-pin VQFN (RHB)
package, orderable part number **`M0G3518QRHBRQ1`**.

> **Status: schematic complete; layout outstanding.** As of 2026-08-04 **KiCad is the primary
> EDA tool for this fork** (EAGLE is end-of-life; the `.sch`/`.brd` pair is frozen for
> backward compatibility only — see [`ReadMe.md`](ReadMe.md)). The former EAGLE-library
> blocker described in earlier revisions of this document is therefore **retired**: stock
> KiCad ships usable land patterns for `U1`, `U5` and `U6`. What remains is real layout work
> — `U1` still carries the old `QFN32` footprint at the STM32 placement, and `U5`/`U6` are
> unplaced. **See §6.1 and §6.2.**
>
> Sections below that describe EAGLE devicesets, `<connects>` blocks or `.brd` placement
> record how the design got here. Apply their *content* (pin mapping, land-pattern
> dimensions) in KiCad; do not edit the EAGLE files.
>
> **Version:** the fork is **v4.0.0** as of 2026-08-04, and the KiCad project is
> `kicad/LibreServo-v4.0.0.*`. Where this document says v2.3.1 it means the frozen EAGLE
> artefacts, which keep the upstream number.

Supersedes [`MSPM0G3507-MCU-swap.md`](MSPM0G3507-MCU-swap.md) (same MSPM0 platform and package,
smaller die), which superseded [`S32K144-MCU-swap.md`](S32K144-MCU-swap.md) and
[`RS485-CANFD-TPM-upgrade.md`](RS485-CANFD-TPM-upgrade.md).

Sources, both local copies, both cited by section throughout:

- **SLASFA6B** — *MSPM0G351x-Q1 Automotive Mixed-Signal Microcontrollers With CAN-FD Interface*,
  November 2024, revised October 2025:
  [`../../Open-Secure-ESC/docs/datasheets/mspm0g3519-q1.pdf`](../../Open-Secure-ESC/docs/datasheets/mspm0g3519-q1.pdf).
  One data sheet covers **both** MSPM0G3519-Q1 and MSPM0G3518-Q1; the filename names only the
  larger part.
- **SLAAE29A** — *Cybersecurity Enablers in MSPM0 MCUs*, January 2023, revised December 2025:
  [`../../Open-Secure-ESC/docs/datasheets/slaae29a.pdf`](../../Open-Secure-ESC/docs/datasheets/slaae29a.pdf).
  The MSPM0G3518 sits in that document's **`M0Gx5 1x`** column of Table 1-2.

---

## 1. Why the MSPM0G351x die

The MSPM0G3507 pass had two acknowledged weaknesses: a security stack materially weaker than the
S32K144 CSEc it displaced, and only 128 KB/32 KB of memory against the S32K144's 512 KB/64 KB.
Moving to the **MSPM0G351x** die closes both while keeping the identical VQFN-32 5 × 5 mm package
and, as shown in §3, **the identical pinout**.

| | S32K144 (superseded) | MSPM0G3507 (superseded) | **MSPM0G3518-Q1 (this pass)** |
| --- | --- | --- | --- |
| Core | Cortex-M4F @ 80/112 MHz | Cortex-M0+ @ 80 MHz | Cortex-M0+ @ 80 MHz, MPU |
| Main flash | 512 KB (ECC) | 128 KB (ECC) | **256 KB (ECC), dual-bank 2 × 128 KB with address swap for OTA** |
| Data flash | 4 KB FlexRAM (EEPROM emu.) | — | **16 KB dedicated data flash bank, ECC** |
| SRAM | 64 KB | 32 KB (parity) | **128 KB** (64 KB ECC/parity + 64 KB) |
| CAN | 3 × FlexCAN, 1 FD | 1 × CAN-FD | 1 × CAN-FD on this package |
| ADC | 2 × 12-bit | 2 × 12-bit 4 Msps, 11 ch | **2 × 12-bit 4 Msps, 16 ch** |
| Serial | 3 LPUART/3 LPSPI/1 LPI2C | 4/2/2 | **5 UART / 2 SPI / 3 I²C** on this package |
| Crypto engine | CSEc, AES-128 | AES basic (no CMAC/GCM) | **AESADV 128/256: GCM/GMAC, CCM/CBC-MAC, CMAC, CBC, CTR** |
| Key storage | SHE key slots | **none** | **KEYSTORE, up to 4 AES keys** |
| Secure boot | HW AES-CMAC | BIM (SW ECDSA) | **CSC + HW AES-CMAC *and* SW ECDSA P-256** |
| Rollback protection | SHE counters | **none** | **hardware monotonic counter** |
| Memory firewalls | — | **none** | **flash write / read-execute / IP-protection, SRAM W^X** |
| Package | LQFP-48, 9 × 9 mm | VQFN-32, 5 × 5 mm | **VQFN-32, 5 × 5 mm, wettable flank** |

Memory figures are from SLASFA6B Table 8-5 (Memory Organization), which lists the MSPM0G3518
and MSPM0G3519 columns separately: for the '3518, Flash Bank 0 = 128 KB and Bank 1 = 128 KB
(256 KB main total), Data Flash Bank = 16 KB, SRAM Bank 0 = 64 KB (ECC/parity) and Bank 1 =
64 KB. §8.9 confirms *"a dual bank of non-volatile flash memory (up to 256kB/512kB total) and a
separate data flash bank (16kB)"*, with *"bank address swap for in-system, over-the-air (OTA)
firmware updates"*.

**The one item that does not improve is the CPU core.** This is still a Cortex-M0+ with no FPU,
where the S32K144 was a Cortex-M4F and the board's *original* STM32F302K8U6 also had an FPU. Any
`float`/`double` math in `Src/LS_*.c` becomes soft-float. The mitigation is the on-die
**MATHACL** accelerator, which on this die covers **SINCOS, ATAN2, SQRT, DIV and MPY32**
(SLASFA6B §8.23) — a better fit for a PID/curve-generation servo loop than the '3507's
DIV/SQRT/MAC/TRIG set — but using it still means **reworking the control loop in fixed-point**,
not recompiling. Budget for that.

## 2. Security stack

This is the section that reverses the previous two passes' conclusions. The MSPM0G3507 lacked a
Customer Secure Code stage, and without CSC it could have no key store, no firewalls and no
monotonic counter. The MSPM0G351x has CSC, and everything gated behind it follows.

SLASFA6B **§8.18 Security** lists, verbatim: debug security; device identify; *"AES-128/256
accelerator with support for GCM/GMAC, CCM/CBC-MAC, CBC, CTR"*; *"flexible firewalls for
protecting code and data"* (flash write-erase protection, flash read-execute protection, flash
IP protection, SRAM write-execute mutual exclusion); *"secure boot"*; *"secure firmware
update"*; *"secure key storage for up to four AES keys"*; *"customer secure code"*;
*"hardware monotonic counter"*; TRNG; and CRC-16/32 with custom polynomial.

### 2.1 Against the S32K144 CSEc that was dropped two passes ago

| | S32K144 CSEc (SHE-class HSM) | **MSPM0G3518** |
| --- | --- | --- |
| Symmetric engine | AES-128, ECB/CBC/CMAC | **AES-128/256 (AESADV): CBC, CFB, OFB, CTR/ICM, CBC-MAC, CMAC, CCM, GCM** |
| Protected key store | Yes, SHE key slots | **Yes — KEYSTORE, up to 4 keys (128-bit ×4 or 256-bit ×2, plus a session key)** |
| Secure boot | Hardware AES-CMAC over image | **Yes — CSC, with hardware AES-CMAC *and* software ECDSA P-256 / SHA2-256** |
| Asymmetric verification | **No** (SHE is symmetric-only) | **Yes — ECDSA P-256** |
| Rollback protection | SHE counters | **Yes — hardware monotonic counter** |
| Memory firewalls / IP protection | Not in SHE scope | **Yes — flash W / RX / IP-protection, SRAM W^X** |
| Field firmware update | Not in SHE scope | **Yes — dual-bank address swap** |
| TRNG | Yes | **Yes, with power-on and continuous health tests, dedicated local LDO** |
| Key slot count | 17 general + 5 special | 4 (+ session key) — **CSEc wins here** |
| Standardisation | SHE 1.1, `M1`–`M5` | Vendor-specific; **PSA-L1 and ISO 21434 targeted**, EVITA-Light |

Net assessment: the MSPM0G3518 **matches or exceeds CSEc on every axis except raw key-slot
count and formal SHE standardisation**, and adds asymmetric verification, IP protection and
OTA-capable dual-bank update that CSEc never had. The security regression flagged in the two
previous documents is closed.

### 2.2 How KEYSTORE actually protects keys

Worth understanding before firmware planning, because it constrains the provisioning flow
(SLAAE29A §4.5, Figure 4-1):

- **Only the CSC can write keys into KEYSTORE**, and only before it calls `INITDONE`.
- After `INITDONE`, the application can tell the AES engine *which* key slot to use, but **can
  never read or write any stored key**. The key travels from KEYSTORE to the AES engine over a
  **private data bus** that is not visible to CPU, DMA or debugger.
- KEYSTORE contents are **wiped on every `BOOTRST`** and the store unlocks for writing; they
  survive `SYSRST` and lower-order resets. So keys are re-deposited from protected flash by the
  CSC on each cold boot — they are not persistent in the key store itself.
- The design explicitly thwarts partial-key-modification attacks (SLASFA6B §8.21).

### 2.3 Provisioning is a one-way door — decide before production

Same warning as the previous pass, and it still applies: locking NONMAIN (static write
protection on the CSC and key region, plus password-protected or disabled mass erase and factory
reset) **permanently** fixes the configuration on that unit. Per SLAAE29A §2.6 / §3.2 this must
be planned before the first production run, not retrofitted. Bench prototypes should be brought
up with the security policies open and locked down only once the flow is proven.

AES throughput for firmware budgeting, AESADV at 80 MHz (SLAAE29A Table 5-3): 128-bit key
**76 cycles / 0.95 µs** per block encrypt, 256-bit key **81 cycles / 1.01 µs**. That is roughly
2–3× faster than the basic AES block on the MSPM0G3507 (Table 5-2: 168 cycles / 2.10 µs).

## 3. Pinout: unchanged from the MSPM0G3507 pass

**The netlist did not move.** SLASFA6B Figure 6-6 (32-pin RHB) has pad-for-pad the same map as
the MSPM0G3507's RHB: pads 1–32 are `PA0`, `PA1`, `NRST`, `VDD`, `VSS`, `PA2`…`PA27`, `VCORE`,
plus the thermal pad. Every function this design uses is available on the same physical pad.

SLASFA6B's Table 6-2 is easier to audit than the '3507's: it has an explicit **`RHB PIN`**
column, so each row below is a direct lookup rather than a cross-reference.

What *did* change is the **IOMUX `PINCM.PF` function codes** — a firmware concern only, but they
must be right in the pin-mux configuration:

| Net | Pin | Pad | Function | PF on '3507 | **PF on '3518** |
| --- | --- | ---: | --- | ---: | ---: |
| `CLK-8MHZ` | `PA6` | 10 | `HFCLK_IN` | 7 | **6** |
| `PWM-4` | `PA4` | 8 | `TIMA0_C3` | 5 | **8** |
| `PWM-2` | `PA22` | 26 | `TIMA0_C1` | 5 | **7** |
| `PWM-3` | `PA24` | 28 | `TIMA0_C3N` | 4 | **5** |
| `PWM-1` | `PA25` | 29 | `TIMA0_C1N` | 6 | 6 |
| `CAN0_TX` | `PA12` | 16 | `CAN0_TX` | 5 | **12** |
| `CAN0_RX` | `PA13` | 17 | `CAN0_RX` | 6 | **12** |
| `UART0_TX` / `UART0_RX` | `PA10` / `PA11` | 14 / 15 | `UART0_TX` / `UART0_RX` | 2 | 2 |
| `SPI_CLK` / `SPI_OUT` / `SPI_IN` | `PA17` / `PA18` / `PA16` | 21 / 22 / 20 | `SPI1_SCK` / `SPI1_PICO` / `SPI1_POCI` | 3 | 3 |
| `SWDIO` / `SWCLK` | `PA19` / `PA20` | 23 / 24 | `SWDIO` / `SWCLK` | 2 | 2 |

### 3.1 Full assignment

Analog functions are non-IOMUX (set `PINCM.PF` = 0). Spares are terminated per Table 6-20
(*"PAx, PBx, PCx — Open; set corresponding pin functions to GPIO and configure unused pins to
output low or input with internal pullup/pulldown resistor enabled"*).

| Pad | Pin | Net | Function (PF) | IO type | Notes |
| ---: | --- | --- | --- | --- | --- |
| 1 | `PA0` | `LED_RED` | GPIO [1] | **ODIO, 5 V-tol** | 20 mA sink — §3.2 |
| 2 | `PA1` | — | *(spare)* | ODIO, 5 V-tol | |
| 3 | `NRST` | `NRST` | reset | Reset | **must be pulled high** — §4 |
| 4 | `VDD` | `+3V3` | power | Power | |
| 5 | `VSS` | `GND` | power | Power | |
| 6 | `PA2` | — | *(spare)* | SDIO | also `ROSC`; SYSOSC FCL option preserved |
| 7 | `PA3` | `LED_GREEN` | GPIO [1] | SDIO | |
| 8 | `PA4` | `PWM-4` | `TIMA0_C3` [8] | SDIO | → `M4.INA` |
| 9 | `PA5` | `EN-Q` | GPIO [1] | SDIO | driver enable, `R11`/`R12` |
| 10 | `PA6` | `CLK-8MHZ` | `HFCLK_IN` [6] | SDIO | from oscillator `U$100` |
| 11 | `PA7` | `LED_BLUE` | GPIO [1] | SDIO | |
| 12 | `PA8` | — | *(spare)* | SDIO | **also `HFCLK_IN` [10]** — second clock-input option |
| 13 | `PA9` | `SEL_SERIAL` | GPIO [1] | HSIO | RS-485 `DE`+`RE` turnaround |
| 14 | `PA10` | `UART0_TX` | `UART0_TX` [2] | **HDIO** | default BSL `BSLTX` |
| 15 | `PA11` | `UART0_RX` | `UART0_RX` [2] | **HDIO** | default BSL `BSLRX` |
| 16 | `PA12` | `CAN0_TX` | `CAN0_TX` [12] | HSIO | → `U6.TXD` (ADM3055E) |
| 17 | `PA13` | `CAN0_RX` | `CAN0_RX` [12] | HSIO | → `U6.RXD` |
| 18 | `PA14` | — | *(spare)* | HSIO | also `A0_12`, `COMP0_IN2+` |
| 19 | `PA15` | `V_CORRIENTE` | `A1_0` (analog) | SDIO | **ADC1**; also `DAC_OUT`, `COMP0/1_IN3+` |
| 20 | `PA16` | `SPI_IN` | `SPI1_POCI` [3] | SDIO | |
| 21 | `PA17` | `SPI_CLK` | `SPI1_SCK` [3] | SDIO (wake) | |
| 22 | `PA18` | `SPI_OUT` | `SPI1_PICO` [3] | SDIO (wake) | also `BSL_invoke` |
| 23 | `PA19` | `SWDIO` | `SWDIO` [2] | SDIO | |
| 24 | `PA20` | `SWCLK` | `SWCLK` [2] | SDIO | |
| 25 | `PA21` | `GND` | `VREF-` (analog) | SDIO | |
| 26 | `PA22` | `PWM-2` | `TIMA0_C1` [7] | SDIO | → `M5.INA` |
| 27 | `PA23` | `VDDA-FILTRADO` | `VREF+` (analog) | SDIO | |
| 28 | `PA24` | `PWM-3` | `TIMA0_C3N` [5] | SDIO | → `M4.INB` |
| 29 | `PA25` | `PWM-1` | `TIMA0_C1N` [6] | SDIO | → `M5.INB` |
| 30 | `PA26` | `V_TEMP` | `A0_1` (analog) | SDIO | ADC0; alt `CAN0_TX` [10] |
| 31 | `PA27` | `V_BAT` | `A0_0` (analog) | SDIO | ADC0; alt `CAN0_RX` [10] |
| 32 | `VCORE` | `VCORE` | core LDO | Power | **0.47 µF tank cap only** — §4 |
| 33 | thermal pad | `GND` | — | — | symbol pin `PAD` |

**Spares: `PA1`, `PA2`, `PA8`, `PA14` (4).**

Motor PWM still lands on two matched complementary `TIMA0` pairs with deadband support —
`PWM-2`/`PWM-1` on `TIMA0_C1`/`C1N`, `PWM-4`/`PWM-3` on `TIMA0_C3`/`C3N` — so the H-bridge can
be driven as complementary PWM or as PWM+direction, as a firmware choice.

### 3.2 Rationale carried over unchanged

The reasoning behind each choice is in [`MSPM0G3507-MCU-swap.md`](MSPM0G3507-MCU-swap.md) and is
still valid because the IO structures are the same on this die (Table 6-1; abs-max Table 7-1:
SDIO 6 mA, HSIO 6 mA, **HDIO 20 mA, ODIO 20 mA sink**):

- **§3.1** `LED_RED` on `PA0` — the RGB is common-anode, `R6` = 187 Ω makes red the
  highest-current channel at roughly 6–8 mA, over the 6 mA standard-drive limit; `PA0` is
  open-drain, 20 mA sink, low-side NMOS only, which is exactly right for pulling a cathode down.
- **§3.2** `HFCLK_IN`, not a crystal — `U$100` is an oscillator module (square wave). Note the
  '3518 additionally offers `HFCLK_IN` on `PA8` [PF10], so unlike the '3507 there is now a
  second external-clock pin available among the spares.
- **§3.3** RS-485 UART on the BSL default pins, with the caveat that the BSL ROM will not drive
  `SEL_SERIAL`, so BSL replies cannot reach the bus without a fixture asserting `DE`.
- **§3.4** ADC split — `V_CORRIENTE` alone on ADC1 so it can be sampled simultaneously with an
  ADC0 channel.
- **§3.5** `VDDA-FILTRADO` → `VREF+`, `VREF-` → `GND`, with `C4` (1 µF) as the required VREF
  decoupling. SLASFA6B §8.15 confirms the same external-reference support and that a decoupling
  capacitor on `VREF+`/`VREF-` is required for proper operation.

## 4. Support components — unchanged

SLASFA6B §7.3 and §9.1 specify exactly the same values as the '3507, so **no BOM change**:

| Ref | Value | Net | Requirement |
| --- | --- | --- | --- |
| `R21` | 47 kΩ 0402 | `NRST` → `+3V3` | §9.1: *"NRST **must** be pulled to VDD for the device to start"*; Table 6-20 repeats it. 47 kΩ is TI's recommended value. |
| `C40` | 10 nF 0402 | `NRST` → `GND` | TI-recommended `NRST` filter (§9.1). |
| `C39` | 470 nF 0402 | `VCORE` → `GND` | §7.3 C<sub>VCORE</sub> = 470 nF; §9.1: *"Do not connect other circuits to the VCORE pin."* |

§7.3 note (1) adds a requirement worth passing to whoever does layout: *"Connect C<sub>VDD</sub>
and C<sub>VCORE</sub> between VDD/VSS and VCORE/VSS respectively, as close to the device pins as
possible. A low-ESR capacitor with at least the specified value and tolerance of ±20% or better
is required."*

## 5. What changed in the schematic this pass

Only the part identity and two signal names. `PCB/LibreServo-v2.3.1.sch`:

- Symbol and deviceset `MSPM0G3507` → `MSPM0G3518`; `U1` value → `M0G3518QRHBRQ1`.
- Pin names `PA12/CAN_TX` → `PA12/CAN0_TX` and `PA13/CAN_RX` → `PA13/CAN0_RX`. SLASFA6B names
  the signals `CAN0_TX`/`CAN0_RX` because the die has two CAN instances on larger packages.
- Nets `CAN_TX`/`CAN_RX` → `CAN0_TX`/`CAN0_RX` to follow. This restores the names the nets had
  before the MSPM0G3507 pass, so relative to the S32K144 baseline they are unchanged.
- Deviceset description and the two on-sheet annotation blocks updated.

Nothing else moved: no wire, junction, instance or support component was touched.

### Verification performed

Machine-checked against the edited file:

- **XML well-formed**; no residual `MSPM0G3507` or `S32K144` references.
- **All 29 connected `U1` pins land on the intended net**, verified against the RHB pad map;
  all 33 symbol pins are unique and resolve to a real pad; the 4 unconnected pins are exactly
  the intended spares.
- **Zero shared connection points between different nets** across the whole sheet — every wire
  endpoint, junction and rotation-resolved pin coordinate was collision-checked.
- **No unresolved references:** every `pinref` resolves to an existing instance and symbol pin.

## 6. Still open

### 6.1 RETIRED: the EAGLE symbol-only-deviceset blocker

**Superseded 2026-08-04 by the move to KiCad.** This subsection previously recorded a hard
blocker: `MSPM0G3518` (`U1`), `ADM2587E` (`U5`) and `ADM3055E` (`U6`) were all merged into the
EAGLE library as **symbol-only devicesets** — empty `package` attribute, no pin-to-pad
`<connects>` — so none of them could be placed or routed on the `.brd`, and the schematic was
not submittable upstream. Hand-authoring three EAGLE packages plus their `<connects>` tables
was the critical path.

That path is abandoned. The EAGLE files are frozen (see [`ReadMe.md`](ReadMe.md)), and stock
KiCad 9 already ships correct, KLC-reviewed land patterns for all three parts:

| Ref | Part | Stock KiCad footprint |
| --- | --- | --- |
| `U1` | MSPM0G3518-Q1, VQFN-32 RHB | `Package_DFN_QFN:Texas_RHB0032E_VQFN-32-1EP_5x5mm_P0.5mm_EP3.45x3.45mm` |
| `U5` | ADM2587E, SOIC-20W | `Package_SO:SOIC-20W_7.5x12.8mm_P1.27mm` |
| `U6` | ADM3055E, SOIC-20W | `Package_SO:SOIC-20W_7.5x12.8mm_P1.27mm` |

Two things to check rather than assume about the `U1` footprint:

1. **It is `RHB0032E`, not `RHB0032T`.** KiCad's library is named for the '3507-era drawing
   revision; the '3518/'3519 datasheet gives `RHB0032T` (4224744/A). Per §6.2 the two are
   equivalent within rounding, but confirm against SLASFA6B §12 before fabrication.
2. **It is not TI's literal recommended pattern.** KiCad's pads are 0.875 × 0.25 mm where
   SLASFA6B §12 specifies 0.62 × 0.25 mm — the KLC pattern extends the pads outward for
   inspectability and hand-rework. Exposed pad (3.45 × 3.45 mm) and 0.5 mm pitch match.
   Pad 1 is in the **left column**, which is the correct orientation for TI's numbering.

The verification caveat carried over from
[`RS485-CANFD-TPM-upgrade.md`](RS485-CANFD-TPM-upgrade.md) "Still missing" still applies in
KiCad: footprint pad geometry *"can look 'done' in an XML diff while being wrong on the
board"*. Open the footprint in the KiCad footprint editor and compare it against the
SLASFA6B §12 mechanical drawing before fabricating — pad 1 orientation above all, because the
legacy Propio `QFN32` numbers from a different corner (§6.2).

The pin-to-pad mapping in §3.1 is unaffected by the tool change and remains the authority for
binding symbol pins to pads, cross-checked against SLASFA6B Table 6-2's `RHB PIN` column.

### 6.2 Footprint and layout

- [x] **Footprint for the RHB package** — resolved by the KiCad move (§6.1): use stock
      `Package_DFN_QFN:Texas_RHB0032E_VQFN-32-1EP_5x5mm_P0.5mm_EP3.45x3.45mm`. Reference
      dimensions retained here for verification. The '3518/'3519 datasheet gives package
      drawing **`RHB0032T` (4224744/A)**, a different revision from the '3507's `RHB0032E`
      (4223442/B); dimensions are equivalent within rounding. TI's recommended land pattern
      (SLASFA6B §12): **32 pads 0.62 × 0.25 mm on 0.5 mm pitch, 4.78 mm row-to-row span,
      3.45 × 3.45 mm exposed thermal pad (pad 33)**, body 4.85–5.15 mm square, 1 mm max
      height. KiCad's pads are 0.875 mm long rather than 0.62 mm — see §6.1 note 2.
- [x] **Pin-to-pad binding** — superseded as an EAGLE `<connects>` task. In KiCad the
      binding is made by assigning the footprint to the symbol; the mapping itself is the
      table in §3.1 and is unchanged.
- [ ] **Promote `#U1` to a real component.** The KiCad EAGLE import turned every
      package-less EAGLE part into a `#`-prefixed pseudo-component — the class KiCad reserves
      for power flags — so `kicad/LibreServo-v4.0.0.kicad_sch` holds `#U1`, `#U5` and `#U6`,
      and no others. Until the `#` is dropped they will not annotate, net-list or reach the
      BOM as real parts.
- [ ] **Correct `U1`'s part number in the KiCad file.** The import predates the '3519 → '3518
      correction: the symbol is `LibreServo-v4.0.0-eagle-import:MSPM0G3519` and the value is
      `M0G3519QRHBRQ1`. The fitted part is the **MSPM0G3518-Q1, `M0G3518QRHBRQ1`** — the
      '3519 is not offered in RHB-32. Rename the symbol and fix the value. (The rest of the
      import is current with the frozen EAGLE master, including the `CAN0_TX`/`CAN0_RX`
      rename from §5.)
- [ ] **Assign the footprint to `U1` in `kicad/LibreServo-v4.0.0.kicad_sch`** and update the
      board. **The legacy Propio `QFN32` footprint is NOT reusable** — its pad 1 is on the
      bottom row where TI's is on the left column (90° apart), and its span is 5.5 mm against
      TI's 4.78 mm. Only the 3.45 mm thermal pad matches.
- [ ] **`U1` placement in `kicad/LibreServo-v4.0.0.kicad_pcb`** — the footprint there is
      still `LibreServo-v2.3.1:QFN32` at the inherited STM32 location (EAGLE
      `x=4.78 y=8.4 rot=R270`). Body size is unchanged at 5 × 5 mm so the envelope fits, but
      pad 1 moves to a different corner, so the escape routing must be redone.
- [ ] **Thermal vias under the exposed pad** — the `_ThermalVias` variant of the stock
      footprint exists; decide between it and the plain variant before routing.
- [ ] **`C1` bulk decoupling is below spec** — §7.3 lists C<sub>VDD</sub> = 10 µF and §9.1
      recommends 10 µF + 0.1 µF within a few millimetres. `C1` is **4.7 µF** in an 0402.
      Raising it to 10 µF in 0402 is severely derated at 3.3 V; this is a real case-size vs.
      capacitance decision, deliberately not changed silently.

### 6.3 Firmware

- [ ] Fixed-point rework of the PID/curve-generation loop (§1), using MATHACL.
- [ ] Full port to the MSPM0 SDK / SysConfig; `Test_LibreServo_v2.ioc` and
      `STM32F302K8UX_FLASH.ld` are dead artefacts.
- [ ] Update the pin-mux configuration to the **'3518 PF codes** in §3, not the '3507's.
- [ ] Decide the secure-boot and KEYSTORE provisioning flow **before** the first production run
      (§2.3) — NONMAIN lockdown is permanent per unit.
- [ ] Confirm what else is live on the shared `SPI_CLK`/`SPI_IN`/`SPI_OUT` bus (`U$4`, `U$6`)
      before enabling hardware SPI1 on it.

### 6.4 Board-level, carried over and still unresolved

- [ ] Footprint assignment (`Package_SO:SOIC-20W_7.5x12.8mm_P1.27mm`, §6.1), 3D models and
      `.kicad_pcb` placement for `ADM2587E` (`U5`) and `ADM3055E` (`U6`) — both are still
      unplaced.
- [ ] **5 V rail for `U6`'s isoPower `VCC`** (`+5V_ISO_CANFD`) — nothing on the board makes 5 V.
- [ ] CAN-FD bus connector strategy; `CANH`/`CANL` are unterminated labelled nets.
- [ ] `ADM2587E` `GND2` copper-separation caveat; isolation creepage/clearance against the
      board outline for the two SOIC-20 isolated parts.
- [ ] Whether the shared `Vmot`/`GND` on the daisy-chain connector undermines RS-485 isolation.

### 6.5 Documentation

- [ ] **Rewrite the README security claims.** They still describe a "post-quantum Trusted
      Platform Module". That was never accurate for the SLB9672, and the part is three
      revisions gone. The accurate claim now is AES-256 with hardware CMAC/GCM, a protected
      key store, CSC secure boot with ECDSA P-256 and AES-CMAC, memory firewalls, and hardware
      rollback protection — PSA-L1 and ISO 21434 **targeted, not yet certified**.
- [ ] `PCB/LibreServo-v2.3_BOM.txt` is **three MCU generations stale** — still lists `U1` as
      `STM32F301K8U6`/`QFN32`, and has none of `ADM2587E`, `ADM3055E`, `C39`, `C40`, `R21`.
      Needs full regeneration from the schematic.
- [ ] This repository has no `CLAUDE.md`/`AGENTS.md`, `TODO.md`, `REFERENCES.md` or
      `PROJECT_INDEX.md`. Citations here follow the in-repo convention (inline, with local
      document path and TI literature number) rather than REF-IDs.

---

## Attribution

Schematic edits, pin assignment, package selection and this document produced by
**Claude Opus 5** (Anthropic), working from the local TI documents SLASFA6B and SLAAE29A.

The 2026-08-04 revision — status banner, §6.1 retirement, and the KiCad items in §6.2/§6.4 —
was also written by **Claude Opus 5**. The decision to make KiCad the primary EDA tool and to
freeze the EAGLE artefacts for backward compatibility was made by the human maintainer.
Device selection (MSPM0G3518-Q1 over MSPM0G3507-Q1, and the VQFN-32 package) was made by the
human maintainer, who also corrected the secure-boot assessment in
[`MSPM0G3507-MCU-swap.md`](MSPM0G3507-MCU-swap.md) §6.

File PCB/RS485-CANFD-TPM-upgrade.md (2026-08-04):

# Hardware upgrade notes: isolated RS-485, isolated CAN-FD, TPM (SLB9672), MCU swap to STM32G431

**Superseded in part**: the STM32G431 (`U1`) and the SLB9672 TPM (`U7`) described in §4/§5 below have since been replaced — `U1` is now an NXP S32K144, and `U7`/SLB9672 has been removed in favor of the S32K144's on-chip CSEc. See [`S32K144-MCU-swap.md`](S32K144-MCU-swap.md) for that pass. The isolated RS-485 (§2, `U5`/ADM2587E) and isolated CAN-FD (§3, `U6`/ADM3055E) content below is still current.

Engineering analysis and part recommendations for the LibreServo v2.3.1 board (`PCB/LibreServo-v2.3.1.sch`, MCU `U1`). This is a decision record and BOM proposal, not yet reflected in the EAGLE `.sch`/`.brd` files — see "Status / next steps" at the bottom for why, and what's needed to finish the layout.

**Decision: MCU is being swapped to STM32G431** (native FDCAN) — see §5. This is the bigger of the two alternatives originally laid out, chosen over adding an external MCP2518FD controller to the existing STM32F302K8U6.

Local datasheet copies for the three parts driving this change are in [`datasheets/`](datasheets/):

- [`ADM2582E-ADM2587E.pdf`](datasheets/ADM2582E-ADM2587E.pdf) — isolated RS-485 transceiver (§2)
- [`ADM3055E-ADM3057E.pdf`](datasheets/ADM3055E-ADM3057E.pdf) — isolated CAN-FD transceiver (§3)
- [`Infineon-SLB9672-TPM2.0-SPI-FW16.xx-datasheet.pdf`](datasheets/Infineon-SLB9672-TPM2.0-SPI-FW16.xx-datasheet.pdf) — TPM (§4)

## 1. MCU CAN-FD capability — verified: no (on the current `U1`, STM32F302K8U6)

`U1` is currently an **STM32F302K8U6** (STM32F302x6/x8 subfamily, Cat.2, UFQFPN32, 64 KB Flash) per `Test_LibreServo_v2.ioc`. This subfamily includes ST's classic **bxCAN** peripheral (CAN 2.0B, up to 1 Mbit/s, 8-byte frames only) — it does **not** implement **FDCAN** (the flexible-data-rate peripheral with BRS and up to 64-byte frames). FDCAN was introduced later, starting with the STM32F7/G0/G4/H7/L5 families ([AN5348, "Introduction to FDCAN peripherals for STM32 MCUs"](https://www.st.com/resource/en/application_note/an5348-introduction-to-fdcan-peripherals-for-stm32-mcus-stmicroelectronics.pdf) lists which families have it — F3 is not one of them).

Practically, this was moot either way for the *current* board: the schematic doesn't route `U1`'s CAN pins anywhere and there's no CAN transceiver in the BOM — CAN is unused silicon on this design today. This is exactly why §5 resolves the gap by swapping to a family that has FDCAN natively, rather than bolting a CAN-FD controller onto silicon that never had CAN wired up in the first place.

**Naming discrepancy worth flagging**: `PCB/LibreServo-v2.3_BOM.txt` lists `U1` as `STM32F301K8U6`, not `STM32F302K8U6` as configured in the `.ioc`. Datasheet: [STM32F301C6](https://www.st.com/resource/en/datasheet/stm32f301c6.pdf) (STM32F301x6/x8 subfamily — same die family, no isolated local copy here as `st.com` isn't reachable from this session's network policy). The two subfamilies share the same bxCAN-only (no FDCAN) conclusion above either way, but whoever does the schematic/footprint pass for the STM32G431 swap (§5) should first confirm which part is actually populated on existing boards (F301 vs. F302 — F302 additionally has a comparator/op-amp/USB set F301 lacks) so the new part is compared against the right baseline.

## 2. Isolated RS-485 transceiver (replaces `U5`, SIT3485EUA)

Current part: `U5`, SIT3485 half-duplex RS-485, MSOP-8, no isolation — the daisy-chain bus (`U$8`/`U$9`, JST-PH-4) shares digital GND directly with every other servo on the chain today.

**Recommendation: Analog Devices [ADM2587E](https://www.analog.com/ADM2587E/datasheet)** (USA, local copy: [`datasheets/ADM2582E-ADM2587E.pdf`](datasheets/ADM2582E-ADM2587E.pdf)). Single-chip signal *and* power isolation (iCoupler + isoPower — no external isolated DC/DC needed), half/full-duplex configurable, ±15 kV ESD, 2.5 kV rms isolation, single 3.3 V or 5 V supply on the logic side, 20-lead wide-body SOIC.

Why this over a signal-only isolator (e.g. TI [ISO1176](https://www.ti.com/product/ISO1176)): board space on this design is very tight, and a signal-only part still needs a separate isolated bus-side supply (push-pull driver + transformer, or a small isolated DC/DC module) — more parts, more area, more failure modes, for a part that's smaller/cheaper only in isolation. If SOIC-20 footprint area turns out to be the binding constraint, ISO1176 + an isolated supply is the fallback.

**Note on what "isolated" actually buys here**: the JST-PH-4 daisy-chain connector carries `Vmot`/`GND` (shared power distribution across the chain) alongside A/B. Isolating the transceiver splits the MCU/digital-logic ground from the RS-485 bus-side reference, which cuts ground-loop coupling and protects against bus miswiring/surges — but it does **not** isolate one servo's power domain from the next, since `Vmot`/`GND` still run straight through the connector by design. True node-to-node galvanic isolation would need the power distribution reworked too; that's a materially bigger change and is out of scope unless you want it.

## 3. Isolated CAN-FD transceiver (new)

**Recommendation: Analog Devices [ADM3055E](https://www.analog.com/media/en/technical-documentation/data-sheets/adm3055e-adm3057e.pdf)** (USA, local copy: [`datasheets/ADM3055E-ADM3057E.pdf`](datasheets/ADM3055E-ADM3057E.pdf)). Same iCoupler/isoPower approach as the ADM2587E above — 5 kV rms signal+power isolation, single 5 V supply, ISO 11898-2:2016 compliant, rated to 5 Mbps CAN FD (up to 12 Mbps demonstrated), 20-lead increased-creepage SOIC.

Picking the same vendor/technology family as the RS-485 part (§2) is deliberate: both isolate power internally, so neither needs its own isolated DC/DC design, and the two parts share a design/verification approach (same iCoupler isolation barrier characterization, same qualification data).

Fallback if SOIC-20 area is a problem: TI [ISO1042](https://www.ti.com/lit/ds/symlink/iso1042.pdf) (signal-only isolation, needs an external isolated supply — same tradeoff as ISO1176 above).

## 4. TPM: Infineon SLB9672

[SLB9672](https://www.infineon.com/assets/row/public/documents/30/49/infineon-slb9672-tpm20-spi-fw16.xx-ds-rev1-3-2024-11-18-datasheet-en.pdf) (Germany/EU, local copy: [`datasheets/Infineon-SLB9672-TPM2.0-SPI-FW16.xx-datasheet.pdf`](datasheets/Infineon-SLB9672-TPM2.0-SPI-FW16.xx-datasheet.pdf)) — TPM 2.0, SPI up to 33 MHz, PG-UQFN-32 package, internal power management (no explicit standby control needed).

Connects to `U1` on **SPI1**. On the new STM32G431 (§5), SPI1 is dedicated to the TPM alone — FDCAN is a separate hardware peripheral with its own TX/RX pins, so there's no bus-sharing between the TPM and the CAN-FD interface as there would have been with the external-controller alternative. Needs one GPIO for `~CS` and ideally one for an interrupt/ready line if the firmware wants event-driven reads rather than polling.

**Pin-budget flag**: still worth a full pin audit once the STM32G431 package/pinout is finalized in EAGLE (motor gate drivers, ADC current sense, encoder, USART1, RGB LED, oscillator, FDCAN TX/RX, and now SPI1 + TPM CS/IRQ all need a home) — the G431 has more GPIO headroom than the F302K8 it's replacing, but it's not unlimited, especially if a similarly small package (e.g. K6/K8, UFQFPN32) is kept for footprint/size parity.

## 5. MCU swap: STM32G431 for native FDCAN

Since §1 confirmed the current `U1` (STM32F302K8U6) has no FDCAN peripheral, an isolated CAN-FD *transceiver* alone isn't sufficient — something has to run the CAN-FD protocol/arbitration. Two options were evaluated; **STM32G431 is the one being taken forward**.

**Decision: [STMicroelectronics STM32G431](https://www.st.com/resource/en/datasheet/stm32g431c6.pdf)** series (e.g. STM32G431K6/K8, UFQFPN32) — HQ Plan-les-Ouates, Switzerland, fabs in France/Italy, **EU**. Cortex-M4 @ up to 170 MHz, native FDCAN peripheral (hardware bit-timing, message RAM, no CPU-mediated SPI framing), and is ST's official successor line to F3 — see [AN5094, "Migrating between STM32F334/303 and STM32G431/G474/G491"](https://www.st.com/resource/en/application_note/an5094-migrating-between-stm32f334303-and-stm32g431g474g491-mcus-stmicroelectronics.pdf).

| | Pros | Cons |
| --- | --- | --- |
| **Design impact** | Hardware FDCAN = precise bit timing, higher achievable throughput, no CPU cycles spent bit-banging SPI framing; frees SPI1 for the TPM alone; more GPIO/peripheral headroom than the F302K8 for future features | Full MCU swap: new schematic symbol/footprint, PCB relayout, and a firmware port (clock tree, HAL/peripheral register differences, re-mapping ADC/TIM/USART pins for existing PID/curve-generation/current-sense code) — the biggest-impact item in this whole upgrade |
| **Sourcing / "reach"** | ST has deep, redundant EU + global distribution (Digi-Key, Mouser, Farnell/element14, RS Components, Arrow); G4 is a current mainstream family with a long support runway, not a legacy part being phased out | Bigger BOM/unit-cost delta than the external-controller alternative; verification/requalification effort (schematic, layout, firmware, EMC) is proportionally larger |
| **REACH/RoHS** | ST publishes REACH SVHC and RoHS declarations for this family as standard | — |

**Alternative considered, not chosen — external CAN-FD controller on the existing MCU**: [Microchip MCP2518FD](https://ww1.microchip.com/downloads/aemDocuments/documents/OTH/ProductDocuments/DataSheets/External-CAN-FD-Controller-with-SPI-Interface-DS20006027B.pdf) (Microchip Technology Inc., Chandler, Arizona, **USA**) — SPI CAN-FD controller, would have sat between `U1`'s SPI1 and the ADM3055E transceiver from §3, keeping the STM32F302K8U6 in place. Pros were smallest change/lowest risk (no MCU footprint or firmware-port rework) and equally solid US sourcing (Digi-Key/Mouser/Arrow/Newark, EAR99, standard REACH/RoHS declarations). Cons were SPI-bus contention/latency vs. a hardware peripheral, a bus shared with the TPM, and CPU overhead servicing SPI transactions per frame instead of DMA-into-a-peripheral-FIFO — the STM32G431's native FDCAN avoids all of that, which is why it was picked instead.

**On "UK-sourced"**: there isn't a UK fabless/IDM vendor making a comparable CAN-FD controller or MCU — UK-based semiconductor firms in this space are mostly IP licensors (e.g. Arm) rather than chip suppliers. If UK sourcing specifically matters (e.g. procurement policy), the practical route is buying the STM32G431 through a UK distributor (Farnell/element14 or RS Components, both UK-headquartered) rather than a UK-origin die.

## Status / next steps

**Update**: the MCU swap, RS-485 transceiver swap, and CAN-FD transceiver addition described above have now been executed at the schematic (netlist) level in `PCB/LibreServo-v2.3.1.sch` — `U1` is now a `STM32G431` instance, `U5` is now an `ADM2587E` instance, and a new `U6` (`ADM3055E`) instance has been added and wired to `U1`'s FDCAN1 pins. **TPM (`SLB9672`) has now also been wired in, as `U7`** — see "TPM wiring" below for the pin-budget audit that drove how it was connected. This section records exactly what changed, the reasoning behind the wiring decisions, and what is still open. Those files are EAGLE 7.6 XML.

### What changed in the schematic

**Devicesets added** (symbol + a package-less placeholder `<device>`, same pattern EAGLE uses for its own `GND`/`+3V3`/`+7V` supply symbols in this library): `STM32G431`, `ADM2587E`, `ADM3055E`, `SLB9672`. No footprint/package exists for any of the four yet — see "Still missing" below, unchanged from before.

**`U1`: STM32F302K8U6 → STM32G431.** All of `U1`'s pre-existing nets were re-pinned onto the new symbol's actual UFQFPN32 pinout (pin-mapped from `datasheets/stm32g431c6.pdf` Table 12, not assumed to line up with the old F302 pinout — it doesn't, only some pins keep the same physical position). Net-for-net:

- Unchanged pins/nets: `VDD_1`/`VDD_2` (`+3V3`), `VSS_1`/`VSS_2`/`EP` (`GND`, note the two `VSS` pins swapped physical corners between the two parts — doesn't matter electrically), `VDDA/VREF+` (`VDDA-FILTRADO`) and the renamed `VSSA` (was `VSSA/VREF-`, `GND`) which both moved to new physical pins, `PF0-OSC_IN` (`CLK-8MHZ`, unchanged position), `PF1-OSC_OUT` and `PG10-NRST` (both still deliberately NC-marked, matching the existing external-oscillator/no-reset-button design), `PB8-BOOT0` (was `BOOT0`, still hard-tied to `GND` exactly as before — the G431 supports boot-mode selection via option bytes instead of the pin, but this schematic keeps the existing pin-strap behavior rather than assuming firmware will set that option byte), all of `PA0`–`PA10`, `PA13`–`PA15`, `PB0`, `PB5`–`PB7` keep their existing signal names (`SPI_CLK`/`SPI_IN`/`SPI_OUT`, `LED_RED/GREEN/BLUE`, `V_TEMP`, `V_CORRIENTE`, `V_BAT`, `PWM-1`/`PWM-3`, `EN-Q`, `USART1_TX/RX`, `SEL_SERIAL`, `SWDIO`/`SWCLK`), though several physically moved pin position (SPI/LED pins in particular).
- **Displaced by FDCAN1**: `PA11` and `PA12` are the *only* FDCAN1 RX/TX-capable pins broken out on the UFQFPN32 package (confirmed against the full alternate-function table in `datasheets/stm32g431c6.pdf` — `PD0`/`PD1`/`PB9`, the other FDCAN1-capable pins, aren't bonded out on this 32-pin package). Those two pins previously carried `PWM-2` and `PWM-4` (motor driver direction inputs). They're now `FDCAN1_RX` (`PA11`) and `FDCAN1_TX` (`PA12`); `PWM-2` and `PWM-4` were moved to `PB4`/`PB3`, which were both **already unused** on the F302 (explicitly NC-marked in the schematic, not carrying any signal) — so this was a like-for-like pin swap with no net pin-budget shortfall, not a compromise. `PA15` was the one spare/NC pin left after that swap — it's now used for `TPM_CS#` (see "TPM wiring" below), which means the UFQFPN32 package is **fully pinned out**: every one of `U1`'s 32 signal pins (plus `EP`) now carries a net, with zero spares remaining.
- **Caveat for firmware**: `PB3`/`PB4` don't have a `TIM1` alternate function on the G431 (unlike some of the pins they're replacing might have implied) — if the motor-PWM firmware needs a specific hardware timer channel on these two lines specifically, that's a firmware-side pin/timer re-assignment to check during the port, not something resolved by this schematic pass.

**`U5`: SIT3485 → ADM2587E** (§2). `RxD`/`TxD` stay wired to `USART1_RX`/`USART1_TX`; `RE`+`DE` are tied together onto `SEL_SERIAL` exactly like the old part's `RE̅`+`DE` (ADM2587E's `RE` is active-low, `DE` active-high — same convention, confirmed against `datasheets/ADM2582E-ADM2587E.pdf` Table 10). `VCC`/`GND1` (logic side) go to the existing `+3V3`/`GND` rails, per the datasheet's 3.3 V-or-5 V flexibility. Configured **half-duplex** per datasheet Figure 38 by tying `Y`+`A` together onto the existing `RS485_P` net and `Z`+`B` together onto `RS485_N`, so the daisy-chain connectors (`U$8`/`U$9`) didn't need to change. Added the datasheet-recommended isoPower support components (all from existing, footprint-complete library devicesets — `C-EU`, `FERRITE_BEAD_0603`): `VCC`/`GND1` decoupling (`C25`/`C26`), and the `VISOOUT`↔`VISOIN` isoPower loop (`B4` ferrite + `C27`–`C30`), referenced to a new, deliberately-isolated `RS485_ISO_GND` net that has **no connection to the board's main `GND`** — that separation *is* the isolation this part is being bought for; bridging it back to `GND` would defeat the purpose. One known limitation carried over from the already-merged symbol (not introduced by this pass): the ADM2587E symbol collapses all of the part's `GND2`-labeled pins (silicon pins 11, 14, 16, 20) onto a single schematic pin, but the datasheet calls out pin 16 as needing to stay off the same copper as pins 11/14 at layout time (EMI/noise separation, not a different net) — that distinction can't be expressed in the schematic as currently drawn and needs to be handled with copper-pour placement when the footprint/layout pass happens.

**`U6` (new): ADM3055E isolated CAN-FD transceiver** (§3). `TXD`/`RXD` go to the new `FDCAN1_TX`/`FDCAN1_RX` nets to `U1`. `VIO` → `+3V3` (matches MCU logic level). `SILENT`/`STBY` tied to `GND` (both are active-high with internal pull-downs — tying them low keeps the part in normal, always-on mode; nothing in this design drives them dynamically). `AUXIN`/`AUXOUT` are genuinely unused and marked NC, same convention as the rest of this schematic. Isolated side: `GND2` directly anchors a new `CANFD_ISO_GND` net (this part's symbol, unlike ADM2587E's, keeps `GND2`/`GNDISO` as separate pins, so the datasheet's noise-separation intent — `GNDISO` reaches the same isolated ground only through a ferrite, `B5` — could actually be followed here); `RS` is shorted to that same isolated ground for full-speed (non-slope-limited) operation, per datasheet §"RS Pin". `VISOOUT`↔`VISOIN` isoPower loop (`B6` + `C35`–`C38`) again referenced only to the isolated ground net, never to board `GND`. **`VCC` (the 4.5–5.5 V isoPower rail) is wired to a new `+5V_ISO_CANFD` net that nothing currently drives** — this board has no 5 V rail today (the existing `MPM3610`→`AP2112` chain only produces the ~3.8 V intermediate feeding `+3V3`; the raw `VMOT`/`+7V` rail is the unregulated battery/motor input voltage, not a regulated 5 V and not safe to feed into `VCC` directly). **A new small 5 V regulator (or a point-of-load buck/LDO tapped off `VMOT`) is required before this part can actually work — deliberately left as an open BOM/regulator-selection decision rather than guessed at here**, same way the MCU swap itself got its own dedicated write-up in §5 instead of being picked casually. `CANH`/`CANL` are brought out as labeled, currently-unterminated nets (`CANH`, `CANL`) — this schematic pass does **not** add a physical bus connector for them. The existing RS-485 daisy-chain connectors (`U$8`/`U$9`, JST-PH-4) are already fully pinned out (`+7V`/`GND`/`RS485_N`/`RS485_P`), and deciding how CAN-FD physically reaches the connector shell — new dedicated connector(s), a larger shared connector, chain topology — is a real mechanical/connector decision with its own tradeoffs that shouldn't be guessed at silently inside an unrelated commit.

**`U7` (new): SLB9672 TPM, and the pin-budget audit behind it** (§4). Before wiring anything, this pass did the "full pin audit" that §4 flagged as still outstanding: every one of `U1`'s 32 UFQFPN32 signal pins was checked against what it already carries. Result — after the FDCAN1 re-pin above, **exactly one pin was free: `PA15`**. Every SPI1-capable pin on this package (confirmed against the alternate-function table in `datasheets/stm32g431c6.pdf`) is already committed to something else:

| SPI1 pin group (AF5) | Pin | Already carries |
| --- | --- | --- |
| Default (NSS/SCK/MISO/MOSI) | `PA4`/`PA5`/`PA6`/`PA7` | `LED_GREEN`/`LED_BLUE`/`V_TEMP`/`V_CORRIENTE` |
| Remap (NSS/SCK/MISO/MOSI) | `PA15`/`PB3`/`PB4`/`PB5` | *(free)*/`PWM-4`/`PWM-2`/`SEL_SERIAL` |

Neither AF5 group is available as a clean 4-pin bus without bumping an already-load-bearing signal (an ADC input, a motor PWM line, or the RS-485 direction control) to some other pin — and there is no other free pin to bump it to. This is a hard constraint of the 32-pin package, not something a more careful net-name choice could route around. Given that, `SLB9672` was wired as follows rather than left unconnected:

- **`SCLK`/`MOSI`/`MISO` join the existing `SPI_CLK`/`SPI_OUT`/`SPI_IN` bus** that already runs from `U1` (`PA2`/`PA1`/`PA0`, bit-banged — those pins aren't SPI1-AF5-capable on the G431 either, so this was already a software/GPIO-driven bus, not a hardware SPI1 peripheral) out to connector `U$4` and to `POTEN_SERVO` (`U$6`). `TXD`→`SPI_OUT` (`U1`'s output leg) and `RXD`→`SPI_IN` (`U1`'s input leg) follow the same direction convention already used for that bus's other two legs. This is standard multi-drop SPI (shared clock/data, per-device chip select) rather than a new pattern — the bus already fans out to two endpoints before this change, so a third with its own `CS#` is consistent with how it's already used. **The caveat that matters for firmware**: this schematic didn't independently re-verify what's actually live on `U$4`/`U$6` — the sheet's own frame text nearby reads "CONNECTOR FFC@0.5mm" / "CONNECTORS JST-PH" with no port-level description of protocol/timing on this specific bus (that detail lives with whatever's wired to those connectors off-sheet, e.g. via `PCB-2`). **Whoever brings up TPM firmware needs to confirm nothing else on this bus is a continuously-polled, timing-sensitive peripheral before sharing it**, and in any case must make sure `TPM_CS#` is only asserted for the duration of a TPM transaction (deasserted/high the rest of the time) so it never contends with whatever else uses `SPI_CLK`/`SPI_IN`/`SPI_OUT`. Note this is a *different* bus from the AEAT-8800 encoder's SSI interface (`SPI_CLK_2`/`SPI_IN_2`/`SPI_OUT_2` via connector `U$3` to `U10` on the separate `PCB-2`) — that one was deliberately left alone since it's explicitly labeled as a live 1–1.2 MHz SSI link on the schematic and sharing it with TPM traffic would risk the position-feedback control loop.
- **`CS#` → the one free pin, `PA15`**, labeled `TPM_CS#`, with a 10 kΩ pull-up to `+3V3` (`R21`) per the datasheet's typical-schematic recommendation for designs (like this one) that don't guarantee `CS#` is at a defined level during power-on/reset — this board's `PG10-NRST` is deliberately NC (no reset circuit), so GPIOs are genuinely undriven until firmware configures them, making that pull-up the difference between "TPM ignores the bus until firmware takes over" and "TPM potentially responds to noise during boot."
- **`VDD`/`GND`** → `+3V3`/`GND`, with the datasheet-recommended decoupling (`C39` 1 µF bulk + `C40`–`C42` 3×100 nF, one per the part's collapsed `VDD`/`GND` pin group — the symbol merges the silicon's 3 physical `VDD` and 4 physical `GND` pins onto one schematic pin each, same simplification already accepted for `ADM2587E`'s `GND2`).
- **`NCI_VDD` → `+3V3`, `NCI_GND` → `GND`** — both per the datasheet's explicit recommendation for these two pins specifically (`Table 13`: "for future use, it is recommended to connect this pin to VDD/GND").
- **`RST#` → `+3V3`** (tied inactive/high). The datasheet shows it normally driven by a host reset signal, but this board doesn't have one to offer — matching the same "no reset button" precedent already accepted for `U1`'s own `PG10-NRST` — so it's tied off rather than left to the pin's weak internal pull-up alone.
- **`NC`, `NCI`, `PIRQ#`, `GPIO_00`/`GPIO_01`/`GPIO_02` → left unconnected** (`NC_MARKER`), matching this schematic's existing no-connect convention. `NC` and `NCI` per the datasheet (`NC` *must* float; `NCI` *may*). `PIRQ#` is open-drain with no internal pull-up and there's no spare GPIO left to route it to — this means firmware must **poll** the TPM rather than use an interrupt, which §4 already flagged as an optional nice-to-have rather than a requirement. `GPIO_00`–`GPIO_02` are the TPM's own auxiliary NV-controlled GPIOs, unused by this design; the datasheet says they may be left unconnected (internal pull-up).

### Still missing

Footprints/packages, devicesets (which pair a symbol with a footprint and map symbol pins to package pads), and 3D models for `STM32G431`, `ADM2587E`, `ADM3055E`, and `SLB9672` (PG-UQFN-32) — none of those exist yet in the `Propio` library, and none of the new instances (`U1`, `U5`, `U6`, `U7`) have board-side (`.brd`) placement yet. Footprint pad geometry (pitch, pad size, courtyard, creepage/clearance for the two isolated SOIC-20 parts) is exactly the kind of thing that can look "done" in an XML diff while being wrong on the board, so that pass still needs doing in EAGLE itself with visual verification against the datasheet mechanical drawings, rather than hand-authored blind. Recommend doing the footprint/deviceset/placement work in EAGLE, using this document and the now-wired schematic as the reference.

The MCU swap also means a firmware port, not just a layout change: `Src/main.c`, `Src/LS_*.c`, and `Test_LibreServo_v2.ioc` all target the STM32F302K8U6's HAL/register set today (ADC1, TIM1/15/16/17, USART1 pin mappings) and will need re-mapping onto the STM32G431's pinout (which, per the wiring above, is **not** a 1:1 physical remap of the old pin assignments), plus new FDCAN and — once the physical PWM pin/timer question above is settled — motor-PWM init code.

Open items for whoever does the layout/firmware pass:

- Footprints/devicesets/3D models and `.brd` placement for `STM32G431`, `ADM2587E`, `ADM3055E`, `SLB9672` (see above).
- Confirm `PB3`/`PB4` (now `PWM-2`/`PWM-4`) have adequate timer/PWM capability for the motor-drive firmware, or re-pin if a specific `TIM1` channel is required.
- Pick the exact STM32G431 part/package (K6 vs K8 flash size) — pinout is already fixed to UFQFPN32 by the schematic work above, so this is now just a flash-size choice, not a package/pin-count one.
- Confirm isolation-barrier creepage/clearance fits the existing board outline for the two SOIC-20 parts (ADM2587E, ADM3055E), and handle the ADM2587E `GND2` copper-separation caveat above at layout time.
- Select and add a 5 V regulator for the new `ADM3055E` isoPower `VCC` rail (`+5V_ISO_CANFD` net) — nothing on the board produces 5 V today.
- Decide the physical CAN-FD bus connector strategy (extend the existing JST-PH-4 daisy chain, add dedicated connector(s), etc.) and terminate the `CANH`/`CANL` nets accordingly.
- Decide whether the isolated-power caveat in §2 (shared `Vmot`/GND on the daisy-chain connector) needs to be addressed, or is acceptable as-is.
- **Confirm what's actually live on the shared `SPI_CLK`/`SPI_IN`/`SPI_OUT` bus** (`U$4`, `POTEN_SERVO`/`U$6`) before bringing up TPM firmware, and implement bus arbitration around `TPM_CS#` (see "TPM wiring" above) — this is the one TPM decision this pass couldn't fully close out from the schematic alone, since the bus's other consumers aren't characterized on-sheet.
- If a fully dedicated TPM SPI bus (rather than sharing `SPI_CLK`/`SPI_IN`/`SPI_OUT`) turns out to be a hard requirement, the only way to get one is a higher-pin-count STM32G431 package (e.g. LQFP48) — the UFQFPN32 chosen for footprint parity has no free pins left after this pass to give TPM a dedicated bus, and that's a footprint/size tradeoff, not something to change silently.
- `PIRQ#` is left unconnected for the same reason (no spare GPIO) — confirm polling the TPM status register is acceptable for the intended use case, or free up a pin (e.g. by dropping something from the board) if interrupt-driven reads are actually needed.
- Place `R21` (TPM `CS#` pull-up) and the TPM decoupling caps (`C39`–`C42`) close to `U7`'s actual pins once its footprint exists — their schematic positions are placeholders.

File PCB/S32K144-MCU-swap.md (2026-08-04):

# Hardware upgrade notes: MCU swap to NXP S32K144, TPM (SLB9672) dropped in favor of on-chip CSEc

> **SUPERSEDED.** `U1` is no longer an S32K144 — it is now a TI **MSPM0G3518-Q1 (VQFN-32,
> `M0G3518QRHBRQ1`)**. See [`MSPM0G3518-MCU-swap.md`](MSPM0G3518-MCU-swap.md) for the current
> design, by way of [`MSPM0G3507-MCU-swap.md`](MSPM0G3507-MCU-swap.md) (an intermediate pass on
> the smaller MSPM0G350x die). Everything below is retained as the decision record for the
> S32K144 pass only.
>
> Three points below are now resolved or reversed:
>
> - The "no verified pin-to-package-pad table" problem in §3/§4 is **gone** — the MSPM0
>   datasheet (SLASF88C §6.2) carries the full per-package pin table, so the new symbol has
>   real, cited silicon pin numbers rather than net labels.
> - The 48-pin LQFP body-size concern in §1/§4 is **moot** — the MSPM0 replacement is a
>   5 × 5 mm VQFN-32, matching the original UFQFPN-32 envelope.
> - The CSEc capability discussion in §2 is **still relevant but now understates the gap**: the
>   MSPM0G3507 has AES + TRNG but no SHE-class HSM at all. See §1 of the new document.

Follow-up to [`RS485-CANFD-TPM-upgrade.md`](RS485-CANFD-TPM-upgrade.md), which took the board from STM32F302K8U6 to STM32G431 and added the Infineon SLB9672 TPM 2.0 as `U7`. This pass replaces the STM32G431 (`U1`) with an **NXP S32K144** and removes `U7` entirely, using the S32K144's built-in **CSEc** (Cryptographic Services Engine) instead of an external TPM. Local datasheet copy: [`datasheets/S32K1xx.pdf`](datasheets/S32K1xx.pdf).

## 1. Why S32K144

NXP (USA, HQ Austin TX / Eindhoven NL, automotive-grade fabs) — S32K1xx is NXP's automotive general-purpose MCU family, ISO 26262 capable up to ASIL-B, and every device in the family (S32K116 through S32K148) ships with the same on-die CSEc hardware security module, so choosing any S32K14x member gets the security requirement "for free" with no separate TPM part. Key specs for S32K144 specifically (from the local datasheet, `Figure 3` / feature-comparison table):

- Arm Cortex-M4F @ 80 MHz (RUN) / 112 MHz (HSRUN), IEEE-754 FPU
- 512 KB flash (ECC), 64 KB system RAM, 4 KB FlexRAM (EEPROM-emulation capable)
- **3x FlexCAN, 1 with CAN-FD** — native hardware CAN-FD, same category of upgrade the STM32G431 swap was chosen for
- 3x LPUART, 3x LPSPI, 1x LPI2C, 2x 12-bit ADC, up to 89 I/O
- **CSEc (Cryptographic Services Engine)** — SHE (Secure Hardware Extension)-compliant hardware crypto module (§4 below)
- Packages: 48-pin LQFP, 64-pin LQFP, 100-pin LQFP, 100-pin MAPBGA — **no 32-pin QFN option** (32-pin QFN exists only for the smaller S32K116/S32K118 subfamily, which lacks CAN-FD and has far less flash/RAM)

**Decision: 48-pin LQFP**, the smallest package S32K144 comes in. This is a step up from the STM32G431's 32-pin UFQFPN — unavoidable, since no S32K144 package is pin-count-competitive with the 32-pin part it replaces. Whoever does the footprint/layout pass needs to confirm the larger body size still fits the existing board outline.

## 2. TPM removed: `U7` (SLB9672) deleted, CSEc used instead

**What was removed**: part `U7` (SLB9672 TPM 2.0), its decoupling (`C39`–`C42`), its `CS#` pull-up (`R21`), the three local `+3V3` supply-symbol instances and one `GND` instance that only existed to feed it, and the six `NC_MARKER` instances wired to its unused pins. The `SLB9672` symbol and deviceset are deleted from the library section of the schematic — nothing references them anymore. The `TPM_CS#` net (which used the STM32G431's one spare pin, `PA15`) is gone too; that signal simply doesn't exist on the new symbol.

**What replaces it**: NXP's **CSEc**, present on every S32K144 die, needs **zero schematic changes** — no external bus, no chip-select, no decoupling, no pull-up. This is a genuine simplification versus the TPM, which needed a dedicated (well, shared — see the prior doc's caveat) SPI leg, a `CS#` pull-up, and its own decoupling network. CSEc capabilities (per NXP `AN5401`, "Getting Started with CSEc Security Module", and the SHE 1.1 spec it implements):

- AES-128 (ECB, CBC, CMAC) in hardware
- Up to 17 general-purpose key slots + 5 special-purpose keys (SECRET_KEY, MASTER_ECU_KEY, BOOT_MAC_KEY, BOOT_MAC, RAM_KEY) — keys live in protected flash, never exposed to the CPU/bus
- Hardware **secure boot**: CSE reads the bootloader/application image via its own bus-master interface, computes an AES-CMAC over it using the boot key, and compares against a stored MAC before release — sequential, parallel, or strict modes
- True random number generation, key derivation (per SHE's `M1`–`M5` message protocol)

**This is a real capability trade-off, not a drop-in replacement, and is worth flagging explicitly**: the project README describes the TPM addition as adding "a post-quantum Trusted Platform Module allowing cryptographic authentication and message signing." CSEc is a **symmetric-only** SHE-class HSM:

| | SLB9672 (TPM 2.0) | S32K144 CSEc |
| --- | --- | --- |
| Symmetric crypto (AES, MAC) | Yes | Yes, hardware-accelerated |
| Asymmetric crypto (RSA/ECC) — signing, key exchange | Yes (TPM 2.0 command set) | **No** |
| Post-quantum algorithms | No (TPM 2.0 spec predates NIST PQC standardization; SLB9672 doesn't claim PQC either) | **No** |
| Remote attestation (PCRs, quotes) | Yes, TCG-standardized | No — no PCR/attestation model |
| Software stack | TCG TSS / TPM2 command interface (broad ecosystem support) | NXP CSEc driver (S32 SDK) / SHE `M1`–`M5` protocol (narrower, vendor-specific) |
| Key storage | TPM-internal, TCG hierarchy | CSEc key slots in protected flash |
| Board complexity | External chip, SPI bus, `CS#`, decoupling | None — on-die, zero extra parts |
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

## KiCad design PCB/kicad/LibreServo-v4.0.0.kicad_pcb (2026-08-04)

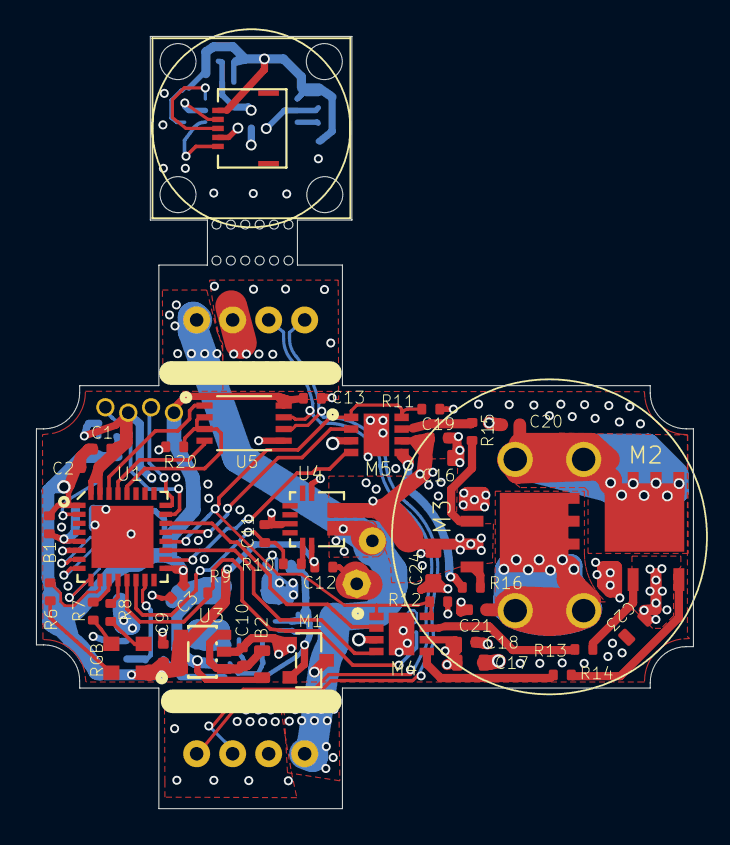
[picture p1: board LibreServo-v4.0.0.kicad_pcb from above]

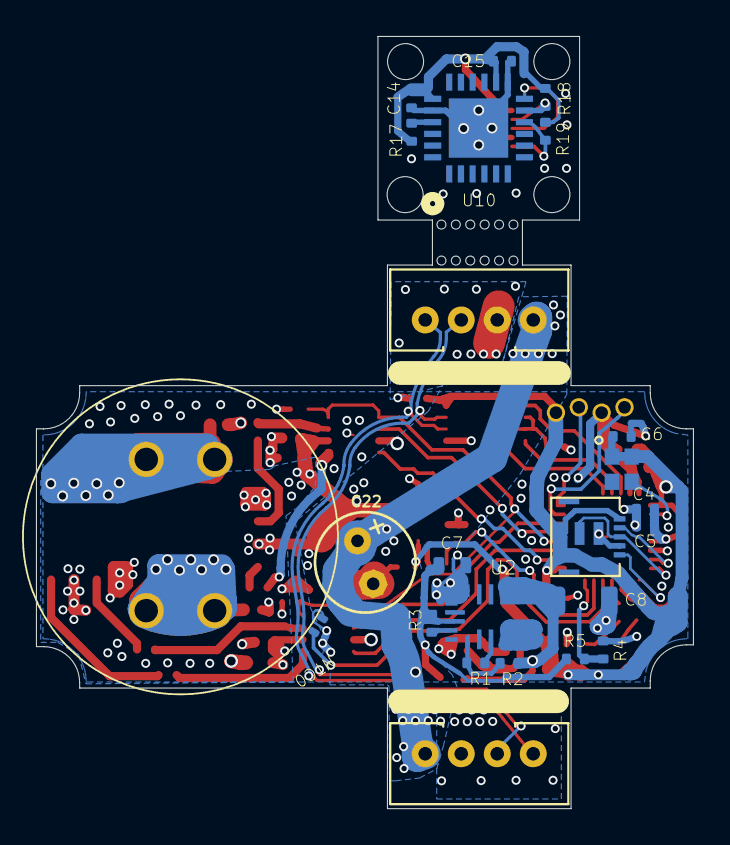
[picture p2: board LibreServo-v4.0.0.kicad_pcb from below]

Board: 6 copper layers, 36.5 x 42.9 mm, 84 parts (23 on the bottom side), 54 nets.

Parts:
B1: 0402
B2: 0603
C1: 4.7u; 0402
C2, C3, C5, C6, C11, C14, C18, C19: 100n; 0402
C4, C9, C10, C12, C13, C15: 1u; 0402
C7, C16, C17, C23, C24: 10u; 0603
C8: 22u; 1206
C20, C21: 10n; 0402
C22: 220uF; E2,5-6_MIN
M1: M1; SOT23
M2, M3: MOSFET_N+P; DFN5X6
M4, M5: FAN3227/4; MLP8
NTC0: 0402_MIN
R1: 12.5K; 0402
R2: 47K; 0402
R3: 150K; 0402
R4, R9, R11, R12, R17, R18, R19, R20: 10K; 0402
R5: 51K; 0402
R6: 187; 0402
R7: 270; 0402
R8: 309; 0402
R10: 1.1k; 0402
R13, R14, R15, R16: 6; 0402
RGB0: LED_RGB_PLCC4_2.2X2; PLCC-4_2.2X2
U1: STM32F301/2; QFN32
U2: MPM3610; MPM36XX
U3: AP2112; SOT25
U4: ACS711; ACS711-QFN
U5: SIT3485; MSOP-8
U10: AEAT-8800; QFN24
U$1, U$2: SLOT; SERVO_SLOT
U$3, U$4: FFC-5; FFC-5-0.5
U$5: HEADER_4_1.27_0.3
U$6: POTEN_SERVO
U$8, U$9: JST_PH-4_HOLEB; JST_PH-4_HOLE_B
U$100: OSCILATOR; OSC-2X1.6
UNK_HOLE_0: dummyfp0
UNK_HOLE_1: dummyfp1
UNK_HOLE_2: dummyfp2
UNK_HOLE_3: dummyfp3
UNK_HOLE_4: dummyfp4
UNK_HOLE_5: dummyfp5
UNK_HOLE_6: dummyfp6
UNK_HOLE_7: dummyfp7
UNK_HOLE_8: dummyfp8
UNK_HOLE_9: dummyfp9
UNK_HOLE_10: dummyfp10
UNK_HOLE_11: dummyfp11
UNK_HOLE_12: dummyfp12
UNK_HOLE_13: dummyfp13
UNK_HOLE_14: dummyfp14
UNK_HOLE_15: dummyfp15

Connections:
711_OUT: R10.2, U4.P$11
+3V3: B1.2, C1.2, C2.2, C3.1, C6.1, C9.1, C12.2, C13.2, R9.2, RGB0.P$1, U1.1, U1.17, U3.5, U4.P$12, U5.P$8, U$4.P$5, U$5.P$1, U$6.P$1, U$100.P$1, U$100.P$4
+3V3_2: C14.1, C15.1, R17.2, R18.1, R19.1, U10.P$14, U10.P$19, U$3.P$1
+7V: C22.+, M1.P$2, U4.P$1, U$8.P$1, U$9.P$1
CLK-8MHZ: U1.2, U$100.P$3
EN-Q: M4.P$1, M4.P$8, M5.P$1, M5.P$8, R11.1, R12.1, U1.20
GND: C1.1, C2.1, C3.2, C4.2, C5.2, C6.2, C7.2, C8.1, C9.2, C10.2, C11.2, C12.1, C13.1, C16.1, C17.1, C18.1, C19.1, C20.2, C21.2, C22.-, C23.2, C24.2, M1.P$1, M2.P$1, M3.P$1, M4.P$3, M4.P$9, M5.P$3, M5.P$9, NTC0.1, R4.1, R11.2, R12.2, R20.2, U1.6, U1.16, U1.31, U1.32, U1.EP, U2.P$12, U2.P$13, U2.P$14, U3.2, U4.P$5, U4.P$7, U4.P$8, U4.P$9, U4.P$10, U5.P$5, U$4.P$2, U$5.P$3, U$6.P$3, U$8.P$2, U$9.P$2, U$100.P$2
GND_2: C14.2, C15.2, U10.P$13, U10.P$20, U10.P$25, U$3.P$4
IN_AP2112: B2.1, C10.1, U3.1, U3.3
LED_BLUE: R8.1, U1.12
LED_GREEN: R7.1, U1.11
LED_RED: R6.1, U1.10
M1-OUT: C7.1, M1.P$3, R3.2, R5.2, U2.P$16
M2-OUT: C20.1, M2.P$5, M2.P$6, M2.P$7, M2.P$8, M2.P$9, U$1.P$1
M3-OUT: C21.1, M3.P$5, M3.P$6, M3.P$7, M3.P$8, M3.P$9, U$2.P$1
M4-OUTA: M4.P$7, R13.2
M4-OUTA-IN: M2.P$2, R13.1
M4-OUTB: M4.P$5, R14.2
M4-OUTB-IN: M2.P$4, R14.1
M5-OUTA: M5.P$7, R15.2
M5-OUTA-IN: M3.P$2, R15.1
M5-OUTB: M5.P$5, R16.2
M5-OUTB-IN: M3.P$4, R16.1
MPM3610_AGND: R1.1, U2.P$3
MPM3610_EN: R3.1, U2.P$17
MPM3610_FB: R1.2, R2.1, U2.P$1
MPM3610_SW: U2.P$4, U2.P$5, U2.P$6
unnamed: R6.2, RGB0.P$4
unnamed: R7.2, RGB0.P$3
unnamed: R8.2, RGB0.P$2
unnamed: R17.1, U10.P$21
OUT_MPM3610: B2.2, C8.2, R2.2, U2.P$7, U2.P$8, U2.P$9
PWM-1: M5.P$4, U1.18
PWM-2: M5.P$2, U1.21
PWM-3: M4.P$4, U1.19
PWM-4: M4.P$2, U1.22
RS485_N: U5.P$7, U$8.P$3, U$9.P$3
RS485_P: U5.P$6, U$8.P$4, U$9.P$4
SEL_SERIAL: R20.1, U1.28, U5.P$2, U5.P$3
SPI_CLK: U1.9, U$4.P$1
SPI_CLK_2: R19.2, U10.P$10, U$3.P$5
SPI_IN: U1.7, U$4.P$4
SPI_IN_2: R18.2, U10.P$11, U$3.P$2
SPI_OUT: U1.8, U$4.P$3, U$6.P$2
SPI_OUT_2: U10.P$12, U$3.P$3
SWCLK: U1.24, U$5.P$2
SWDIO: U1.23, U$5.P$4
USART1_RX: U1.30, U5.P$1
USART1_TX: U1.29, U5.P$4
VDDA-FILTRADO: B1.1, C4.1, C5.1, U1.5
VMOT: C16.2, C17.2, C18.2, C19.2, C23.1, C24.1, M2.P$3, M3.P$3, M4.P$6, M5.P$6, U4.P$3
V_BAT: R4.2, R5.1, U1.15
V_CORRIENTE: C11.1, R10.1, U1.14
V_TEMP: NTC0.2, R9.1, U1.13

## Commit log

2026-08-01 Add engineering notes for isolated RS-485/CAN-FD + TPM upgrade
    Verifies the STM32F302K8U6 has no FDCAN peripheral (bxCAN classic
    only, and unused on this board today), recommends ADM2587E/ADM3055E
    for isolated RS-485/CAN-FD and the Infineon SLB9672 for TPM, and
    lays out two US/EU-sourced alternatives (external MCP2518FD
    controller vs. STM32G431 MCU swap) for adding CAN-FD protocol
    support, with sourcing and REACH/RoHS notes for each.
2026-08-01 Decide on STM32G431 MCU swap for native FDCAN
    Promotes the STM32G431 alternative from §5 to the chosen path over
    the external MCP2518FD controller, and updates the TPM/pin-budget
    notes and open items to reflect that this is now an MCU swap (new
    footprint, pinout remap, firmware port) rather than a same-MCU
    add-on.
2026-08-01 Add ADM2587E, ADM3055E, and SLB9672 datasheets
    Adds local copies of the datasheets for the parts recommended in
    PCB/RS485-CANFD-TPM-upgrade.md (isolated RS-485, isolated CAN-FD,
    and TPM), and links them from that doc.
2026-08-01 Flag STM32F301 vs STM32F302 naming discrepancy in BOM vs .ioc
    The BOM text lists U1 as STM32F301K8U6 while Test_LibreServo_v2.ioc
    configures STM32F302K8U6. Cites the STM32F301C6 datasheet (same
    subfamily) for reference; not mirrored locally since st.com isn't
    reachable from this session's network policy.
2026-08-01 Add EAGLE schematic symbols for ADM2587E, ADM3055E, SLB9672
    Pin-mapped from the three datasheets in PCB/datasheets/ into the
    Propio library's <symbols> section: ADM2587E (isolated RS-485
    transceiver, 20-lead SOIC), ADM3055E (isolated CAN-FD transceiver,
    20-lead SOIC), and SLB9672 (TPM 2.0, PG-UQFN-32). Physically
    duplicated same-net pins (e.g. repeated GND pins) are collapsed onto
    a single symbol pin, matching the library's existing convention.
    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
    [LibreServo-v2.3.1.sch]
2026-08-01 Add EAGLE schematic symbol for STM32G431 (UFQFPN32)
    Pin-mapped from the newly added PCB/datasheets/stm32g431c6.pdf
    (Table 12 pin definition, UFQFPN32 column) into the Propio library's
    <symbols> section, using the same UFQFPN32 package outline/pin-walk
    geometry as the existing STM32F302K8 symbol. Named at the family
    level (STM32G431, not K6/K8) since flash size doesn't affect the
    pinout and is still an open item per this doc.
    Also merges in the user's direct push of the datasheet file to
    master.
    Claude-Session: https://claude.ai/code/session_014MLjLLpWwhDAE1QDFN7CxK
    [LibreServo-v2.3.1.sch]
2026-08-02 Wire MCU/RS-485 swap and CAN-FD addition into the schematic
    Executes the decisions from PCB/RS485-CANFD-TPM-upgrade.md at the
    netlist level in PCB/LibreServo-v2.3.1.sch:
    - U1: STM32F302K8U6 -> STM32G431. Every existing net is re-pinned onto
    the G431's actual UFQFPN32 pinout (verified against the datasheet's
    alternate-function table, not assumed to match the old part).
    PA11/PA12 are the only FDCAN1-capable pins on this package, so the
    PWM-2/PWM-4 signals that used to live there move to PB3/PB4, which
    were already unused (NC-marked) on the F302 - a like-for-like swap
    with no pin-budget shortfall.
    - U5: SIT3485 -> ADM2587E isolated RS-485 transceiver, wired
    half-duplex (Y+A / Z+B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
    [LibreServo-v2.3.1.sch]
2026-08-02 Wire TPM (SLB9672) into the schematic as U7
    Adds the SLB9672 deviceset (symbol-only placeholder, same pattern as
    STM32G431/ADM2587E/ADM3055E) and instantiates it as U7, closing out the
    one item the previous MCU/RS-485/CAN-FD pass deliberately left open.
    A full pin-budget audit of U1 (STM32G431, UFQFPN32) found the package
    fully committed after the FDCAN1 re-pin: every SPI1-capable pin (both
    the PA4-7 default group and the PA15/PB3-5 remap group) already
    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
    [LibreServo-v2.3.1.sch]
2026-08-03 Swap MCU to NXP S32K144, drop SLB9672 TPM for on-chip CSEc
    U1 changes from STM32G431 to S32K144 (48-pin LQFP, no 32-pin package
    exists for this family) at the schematic/netlist level: symbol and
    deviceset renamed, all nets re-pinned net-for-net (pin positions kept
    identical to avoid re-touching wire geometry), CAN-FD/UART/debug nets
    renamed to S32K144 peripheral naming (FlexCAN0, LPUART1, SWD).
    U7 (SLB9672 TPM 2.0) and its support components (decoupling, CS# pull-up,
    local supply/GND instances, NC markers) are removed entirely, along with
    the SLB9672 symbol/deviceset -- the S32K144's built-in CSEc hardware
    security module needs no external pins or bus.
    Documented in PCB/S32K144-MCU-swap.md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
    [LibreServo-v2.3.1.sch]
2026-08-03 mcu symbol
    [LibreServo-v2.3.1.sch]
2026-08-03 do the swap
    [LibreServo-v2.3.1.sch]
2026-08-04 lots of stuff
    [LibreServo-v2.3.1.kicad_pcb, LibreServo-v2.3.1.kicad_sch, LibreServo-v2.3.1.sch]
2026-08-04 clean up
    [LibreServo-v4.0.0.kicad_pcb, LibreServo-v4.0.0.kicad_sch]

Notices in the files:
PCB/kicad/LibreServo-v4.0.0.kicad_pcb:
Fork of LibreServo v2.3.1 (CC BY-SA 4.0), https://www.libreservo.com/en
